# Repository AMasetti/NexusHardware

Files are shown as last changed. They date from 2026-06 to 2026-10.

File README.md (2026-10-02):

# NexusHardware

CAD, print-ready STLs, bill of materials, wiring and datasheets for the Optimus biped robot. Reference-only — no firmware or code lives here.

Related repos: [NexusFirmware](https://github.com/AMasetti/NexusFirmware) · [NexusSimulation](https://github.com/AMasetti/NexusSimulation) · [NexusFuturespace](https://github.com/AMasetti/NexusFuturespace)

---

## Optimus Biped Robot

8-DOF biped with MG995 leg servos and Futaba S3003 arm servos.

| Component | Part | Notes |
|---|---|---|
| MCU | ESP32-C3 Super Mini | Firmware in [NexusFirmware](https://github.com/AMasetti/NexusFirmware) |
| Servo driver | PCA9685 16-ch PWM | I2C @ 0x40 |
| IMU | MPU6050 | I2C @ 0x68 |
| Leg servos ×8 | MG995 | PWM 600–2650 µs |
| Arm servos ×6 + hip yaw | Futaba S3003 | PWM 900–2100 µs |

Leg geometry: femur 90mm → knee → tibia 90mm → ankle → foot 30mm.

Full parts list in [`BOM.csv`](optimus-biped-robot/BOM.csv); pinout and power distribution in [`wiring.md`](optimus-biped-robot/wiring.md).

---

## File structure

```
NexusHardware/
├── optimus-biped-robot/
│   ├── STL/          # Print-ready STL files for all body parts
│   ├── STEP/         # Source CAD (editable in Fusion 360, FreeCAD, etc.)
│   ├── BOM.csv       # Bill of materials
│   └── wiring.md     # Wiring and power distribution
└── datasheets/       # Component datasheets
```

---

## Printing notes

- All STLs are sized for FDM printing in PLA or PETG.
- STEP files are the editable source; modify these if you need to adjust tolerances.

---

## MuJoCo meshes

Lower-resolution copies of the STLs live in [NexusSimulation](https://github.com/AMasetti/NexusSimulation) under `optimus/urdf/full/meshes/` for the MuJoCo model. If you update a part, re-export both.

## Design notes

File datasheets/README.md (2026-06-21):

# Datasheets

| Component | File | Source |
|---|---|---|
| ESP32-C3 MCU | [ESP32-C3-datasheet.pdf](ESP32-C3-datasheet.pdf) | Espressif official |
| PCA9685 16-ch PWM driver | [PCA9685-pwm-driver.pdf](PCA9685-pwm-driver.pdf) | NXP / Adafruit mirror |
| MPU6050 6-axis IMU | [MPU6050-imu.pdf](MPU6050-imu.pdf) | InvenSense / TDK |
| MG995 metal-gear servo | [MG995-servo.pdf](MG995-servo.pdf) | Tower Pro |

Futaba S3003 has no official public datasheet PDF. Key specs: 900–2100 µs pulse, 4.8–6V, ~3.2 kg·cm at 4.8V, ~0.19 s/60°.

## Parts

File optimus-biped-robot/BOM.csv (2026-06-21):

Component | Part Number | Quantity | Supplier | Unit Cost (USD) | Notes
MCU | ESP32-C3 Super Mini | 1 | AliExpress / Amazon | ~3 | Single-core 160 MHz; native USB-CDC; no USB-UART chip
PWM Servo Driver | PCA9685 16-ch | 1 | AliExpress / Adafruit | ~2–5 | I2C 0x40; 50 Hz PWM; drives all 15 servos
IMU | MPU6050 | 1 | AliExpress / Adafruit | ~1–3 | I2C 0x68; 6-axis accel + gyro; complementary filter in firmware
Leg Servo | MG995 (Metal Gear) | 8 | AliExpress / Amazon | ~4–6 each | PWM 600–2650 µs; torque ~13 kg·cm; ch 0–3 and 12–15
Arm Servo | Futaba S3003 | 7 | eBay / secondhand | ~5–10 each | PWM 900–2100 µs; ch 4–10 (6 arm DOF + hip yaw)
LiPo Battery | 2S 7.4V 2200mAh | 1 | HobbyKing / Amazon | ~15–25 | Servo power rail; adequate for ~15 min operation at moderate load
DC-DC Buck Converter | LM2596 / MP1584 | 1 | AliExpress | ~1–2 | Steps 7.4V → 5V for ESP32-C3 and PCA9685 logic
Micro USB / USB-C Cable | — | 1 | — | — | Flashing and serial monitor; ESP32-C3 Super Mini uses USB-C
I2C Pull-up Resistors | 4.7 kΩ | 2 | Generic | <0.01 each | SDA and SCL lines; may be omitted if PCA9685 module has on-board pull-ups
Pin Headers / Dupont Wires | — | assorted | AliExpress | ~2–5 | Servo JST → PCA9685 channel header connections
M2 / M3 Screws and Nuts | — | assorted | Hardware store | ~3–5 | Frame assembly; STL parts designed for M2 inserts and M3 bolts
3D Printed Frame | — | 1 set | Self-printed (PLA/PETG) | ~5–15 filament | STL files in hardware/optimus-biped-robot/STL/; STEP source in STEP/

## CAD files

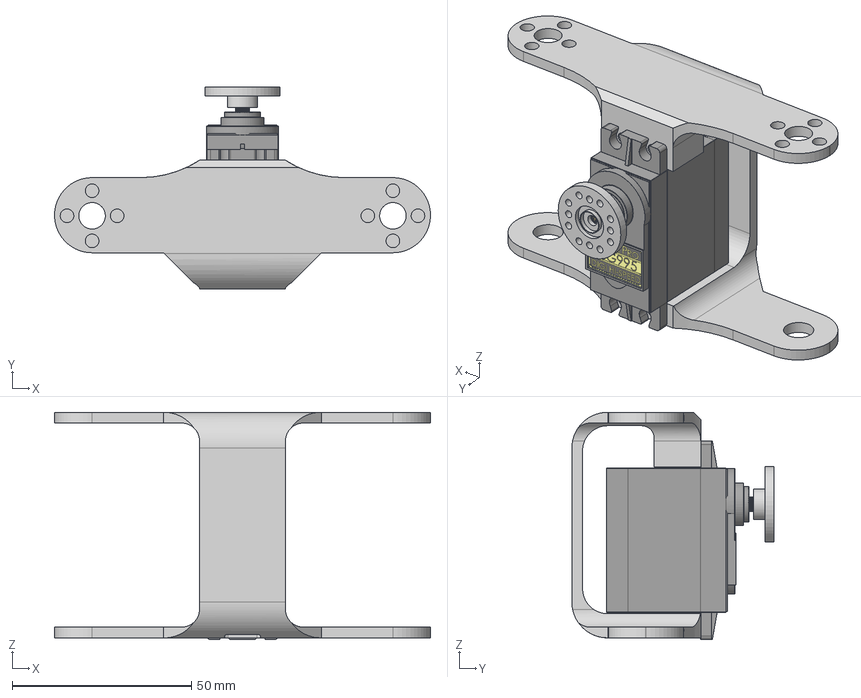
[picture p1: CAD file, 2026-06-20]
optimus-biped-robot/STEP/Hip Assembly.step
105.0 x 56.5 x 63.5 mm
ServoWheel
MG-995 STEP model

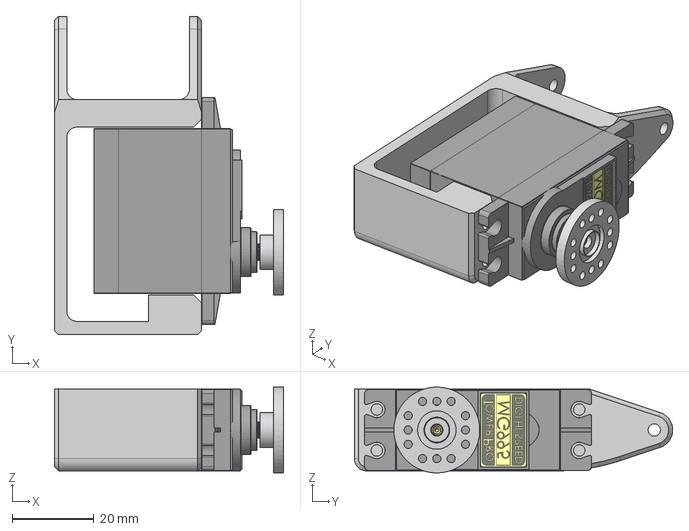
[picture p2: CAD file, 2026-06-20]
optimus-biped-robot/STEP/Sartorius Left - Lower.step
56.0 x 77.8 x 21.0 mm
ServoWheel v1(Mirror)
MG-995 STEP model v1(Mirror)

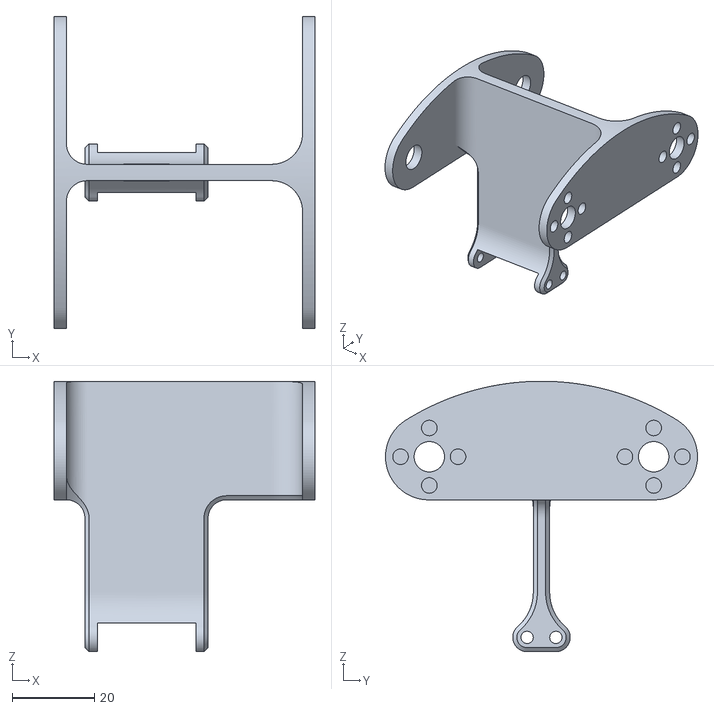
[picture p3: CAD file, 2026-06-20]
optimus-biped-robot/STL/Knee L.stl
63.5 x 76.0 x 65.9

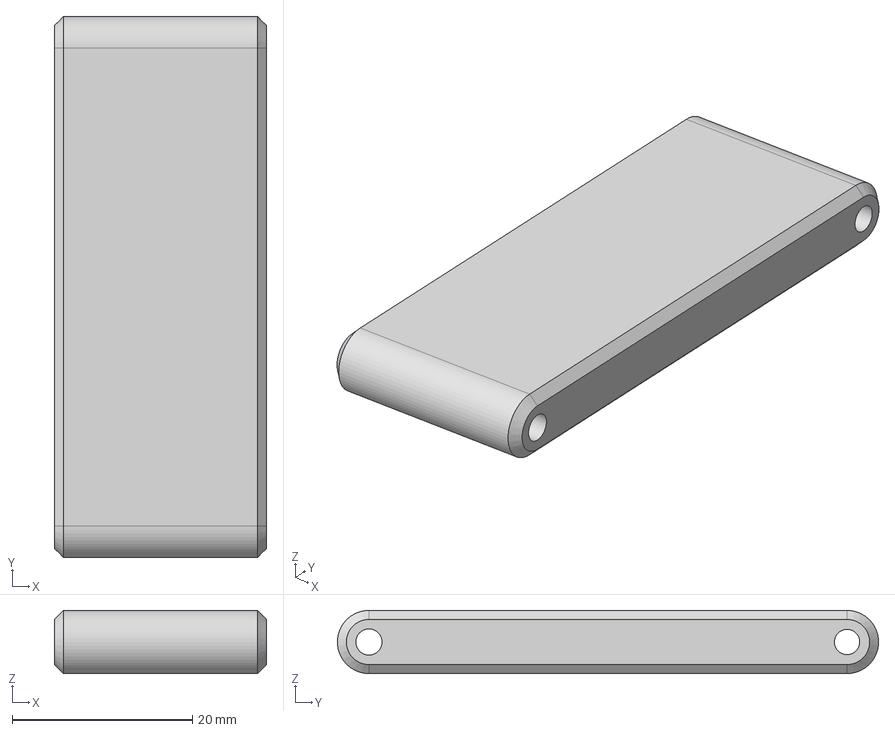
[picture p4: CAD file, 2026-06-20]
optimus-biped-robot/STEP/Tendon LB.step
23.5 x 60.0 x 7.00 mm

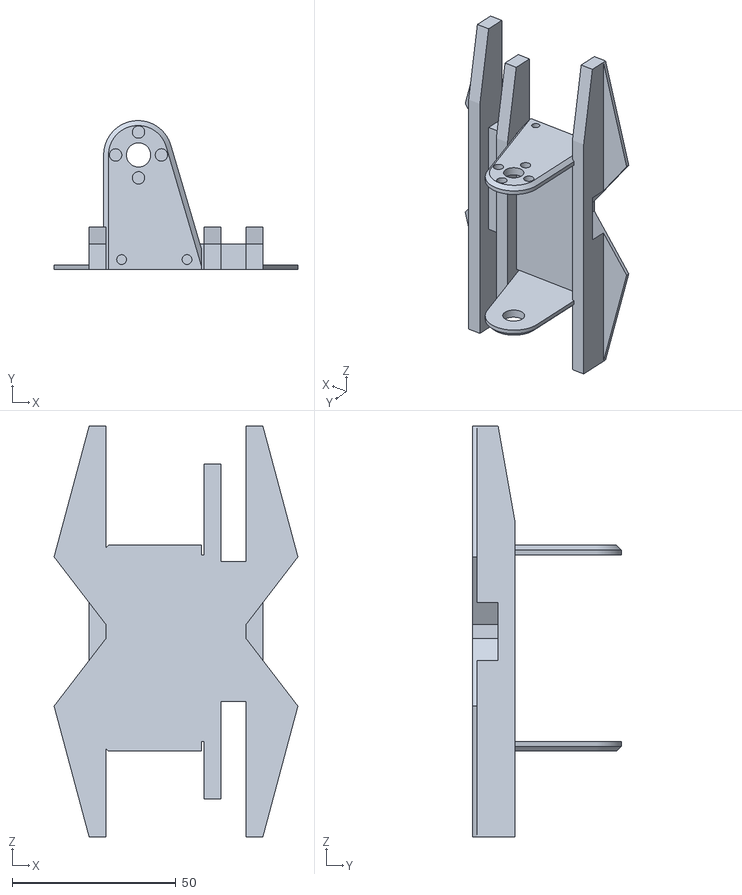
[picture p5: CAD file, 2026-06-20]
optimus-biped-robot/STL/Feet L.stl
74.6 x 45.5 x 125.7

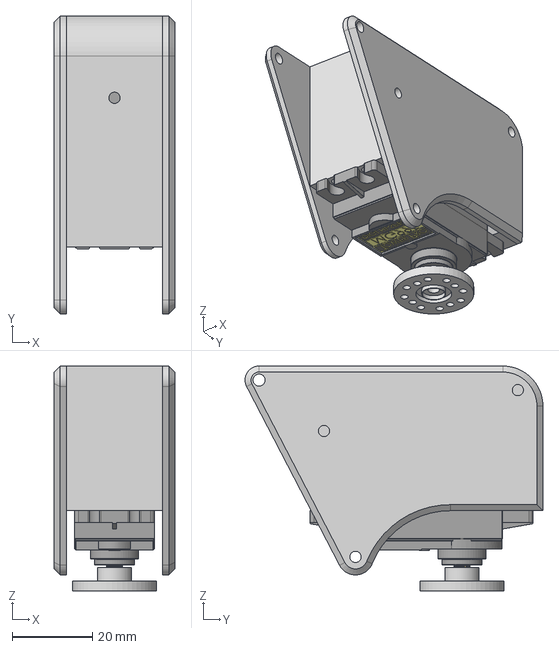
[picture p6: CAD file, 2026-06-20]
optimus-biped-robot/STEP/Hip Right.step
30.0 x 74.1 x 56.0 mm
MG-995 STEP model v1(Mirror) (1)
ServoWheel v1(Mirror) (1)

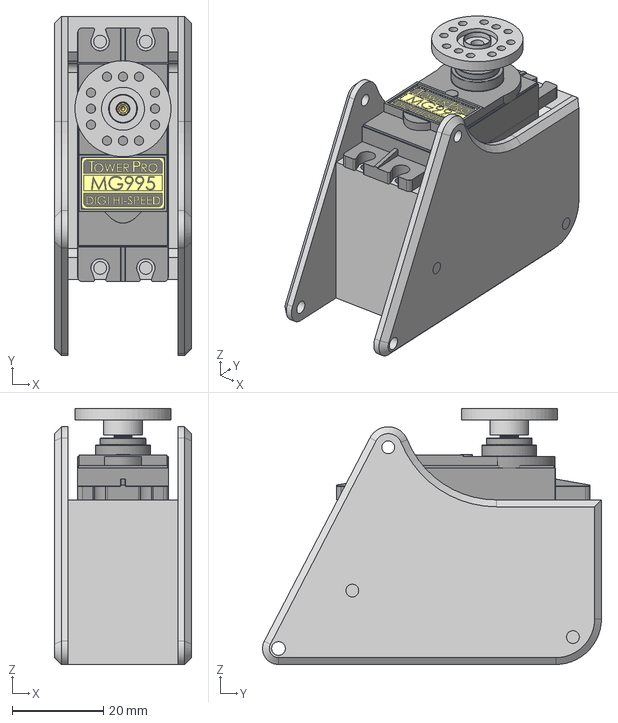
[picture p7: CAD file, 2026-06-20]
optimus-biped-robot/STEP/Knee Right.step
30.0 x 74.1 x 56.0 mm
MG-995 STEP model v1(Mirror)(Mirror)
ServoWheel v1(Mirror)(Mirror)

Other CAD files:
optimus-biped-robot/STL/Feet R.stl
optimus-biped-robot/STEP/Feet Left.step
optimus-biped-robot/STL/Knee R.stl
optimus-biped-robot/STEP/Sartorius Left - Upper.step
optimus-biped-robot/STEP/Tendon RB.step
optimus-biped-robot/STEP/Feet Right.step
optimus-biped-robot/STEP/Tendon RT.step
optimus-biped-robot/STEP/Knee - Left.step
optimus-biped-robot/STEP/Sartorius Right - Upper.step
optimus-biped-robot/STEP/Sartorius Rigth - Lower.step
optimus-biped-robot/STEP/Hip Left.step
optimus-biped-robot/STEP/Knee Left.step
optimus-biped-robot/STEP/Tendon LT.step
optimus-biped-robot/STL/Tendon LB.stl
optimus-biped-robot/STL/Tendon LT.stl
optimus-biped-robot/STL/Tendon RB.stl
optimus-biped-robot/STL/Tendon RT.stl

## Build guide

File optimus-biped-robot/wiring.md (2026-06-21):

# Optimus — Wiring Reference

## ESP32-C3 Super Mini GPIO Pinout

| GPIO | Function | Connected to |
|---|---|---|
| GPIO 8 | I2C SDA | PCA9685 SDA, MPU6050 SDA |
| GPIO 9 | I2C SCL | PCA9685 SCL, MPU6050 SCL |
| USB-C | Flash / Monitor | Host PC (arduino-cli upload / serial monitor) |

All other GPIOs unused. I2C bus runs at 400 kHz (`I2C_FREQ_HZ 400000`).

---

## I2C Bus Topology

Both the PCA9685 and MPU6050 share the same I2C bus (SDA=GPIO8, SCL=GPIO9).

```
ESP32-C3
  GPIO 8 (SDA) ──┬── PCA9685 SDA  (addr 0x40)
                 └── MPU6050 SDA  (addr 0x68)

  GPIO 9 (SCL) ──┬── PCA9685 SCL
                 └── MPU6050 SCL

  3.3V ──────────┬── PCA9685 VCC (logic)
                 └── MPU6050 VCC

  GND ───────────┬── PCA9685 GND
                 └── MPU6050 GND
```

Add 4.7 kΩ pull-up resistors from SDA and SCL to 3.3V if not present on the module boards.

---

## PCA9685 Channel Map

PWM frequency: 50 Hz. All angles measured from servo center (90° = halt).

### Leg Servos — MG995 (600–2650 µs)

| Ch | Joint | Firmware name | `set_inverse` | Halt° | Notes |
|----|---|---|:---:|---:|---|
| 0  | R ankle_roll | `r_ankle_roll` | No | 90 | |
| 1  | R knee | `r_knee` | No | 80 | |
| 2  | R hip_pitch | `r_hip_pitch` | **Yes** | 100 | Inverted axis |
| 3  | R hip_roll | `r_hip_roll` | **Yes** | 100 | Inverted axis |
| 12 | L hip_roll | `l_hip_roll` | No | 80 | |
| 13 | L hip_pitch | `l_hip_pitch` | No | 90 | |
| 14 | L knee | `l_knee` | **Yes** | 90 | Inverted axis |
| 15 | L ankle_roll | `l_ankle_roll` | **Yes** | 70 | Inverted axis |

Channels 11 are unused.

`set_inverse=Yes` means the servo is mechanically mirrored — the firmware negates the angle before writing the pulse.

**Ankle constraint:** `ankle_roll = −hip_roll` always (keeps foot flat). Do not break this in firmware.

### Arm Servos — Futaba S3003 (900–2100 µs)

| Ch | Joint | Firmware name | Dir | T-pose° |
|----|---|---|:---:|---:|
| 4  | R shoulder forward/backward | `r_shoulder_fb` | +1 | 90 |
| 5  | R shoulder lateral elevation | `r_shoulder_lat` | +1 | 90 |
| 6  | R forearm lateral elevation | `r_forearm_lat` | +1 | 90 |
| 7  | L shoulder forward/backward | `l_shoulder_fb` | +1 | 90 |
| 8  | L shoulder lateral elevation | `l_shoulder_lat` | +1 | 90 |
| 9  | L forearm lateral elevation | `l_forearm_lat` | +1 | 90 |
| 10 | Hip yaw (waist rotation) | `hip_yaw` | +1 | 90 |

All arm servos are at their mechanical center (1500 µs) in T-pose. No trim offsets required.

---

## Power Rail Diagram

```
LiPo 2S 7.4V
     │
     ├── DC-DC Buck (→ 5V) ─── ESP32-C3 5V pin  (logic)
     │                     └── PCA9685 VCC servo rail
     │
     └── PCA9685 V+ (servo power)
              │
              ├── ch 0–3, 12–15  → MG995 ×8  (legs)
              └── ch 4–10        → Futaba S3003 ×7  (arms + hip yaw)
```

**Servo power and logic power are separated at the PCA9685 board:**
- `VCC` pin = 3.3V or 5V logic supply (from ESP32-C3 or buck converter)
- `V+` screw terminal = servo power supply (direct from LiPo or 5V regulated)

MG995 stall current is ~1.2A per servo; 8 servos simultaneous stall ≈ 9.6A peak.
Use wire gauge appropriate for expected current (≥22 AWG for servo rails, ≥18 AWG for main lipo lead).

---

## Servo Tuning

Per-servo trim offsets are in `optimus/firmware/include/config.h` under `SERVO_OFFSET_DEG_*`.
Adjust these to compensate for mechanical misalignment after assembly.
Run `make compile-upload` after any change and verify with `make monitor`.

---

## Datasheets

See [`hardware/datasheets/`](../datasheets/README.md) for PDFs: ESP32-C3, PCA9685, MPU6050, MG995.

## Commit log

2026-06-20 init: initial commit of NexusHardware
    CAD files, STLs, schematics and datasheets for Optimus and Tini Biped robots.
    [16 Channel I2C Servo Controller.step, Abductor L.stl, Back Feet Bracket L.stl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]
2026-06-20 refactor: rename folders to kebab-case
    [16 Channel I2C Servo Controller.step, Abductor L.stl, Back Feet Bracket L.stl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]
2026-06-21 docs: add BOM, wiring reference, and component datasheets for Optimus
    [BOM.csv]
2026-10-02 chore: remove archived Tini biped, stop tracking third-party CAD models
    [16 Channel I2C Servo Controller.step, Abductor L.stl, Back Feet Bracket L.stl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]
